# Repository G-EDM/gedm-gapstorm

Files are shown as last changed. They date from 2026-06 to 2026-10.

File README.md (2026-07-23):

</br>
</br>
</br>

```diff
 ______     _______ ______  _______
|  ____ ___ |______ |     \ |  |  |
|_____|     |______ |_____/ |  |  |      

Gapstorm Router
```                                                               

</br>
</br>

# Updates 

07.07.2026 - Updated the links to the most recent freecad project file
* Y-Bracket was missing the holes for the screws (fixed)
* X Ballscrew changed to 400mm
* X Linear rail changed to 300mm
* Some minor changes on the X motor bracket for better assembly

12.07.2026 - Updated the links to the most recent freecad project file
* Mountingbracket for the Y ballscrew support block has changed. It needs to be a little more flexible for adjustments. Replaced the hex nut with T-Nuts and made the screw holes longer.

16.07.2026 - Updated the links to the most recent freecad project file
* Changed the wire outlet. Tube moves now further down and the wire catch area is smaller. Ensure the inlet section is smooth and the 4mm tube goes all the way down.

</br>
</br>

# FreeCAD project file

[Download the G-EDM Gapstorm Router FreeCAD file](https://drive.google.com/file/d/1vxY4w9fKLjqJ0D5UH6L_XMELY-WSWKXv/view?usp=drive_link)
</br>
</br>

# About this Repo

* This Repo contains the files for the mechanical aspect of the G-EDM project. It is not fully finished and not everything is documented. A BOM for the full wire module is included but not for the router. Making the router is not so hard and the components like extrusion, tank, linear rails, ballscrews are all labeled with dimensions inside the FreeCAD project file. The BOM for the wire module is complete and building it is very straight forward. A little youtube video provides a view on the C-Arc from all perspectives.
    
</br>

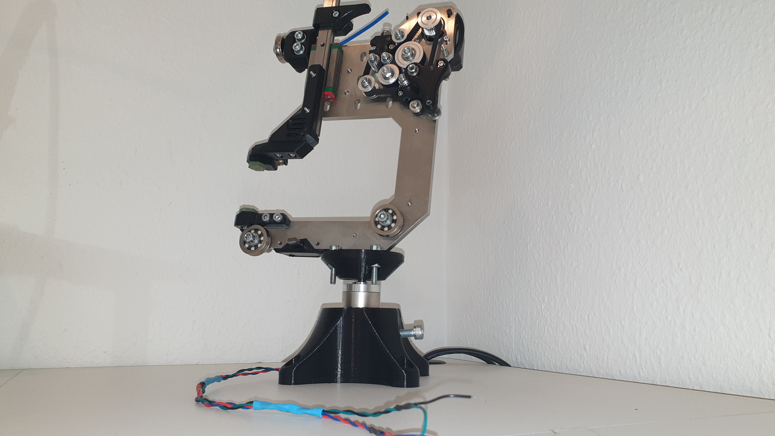
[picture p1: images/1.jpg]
PhantomEDM demo video (https://www.youtube.com/watch?v=hlrt1KqOiBo)

</br>

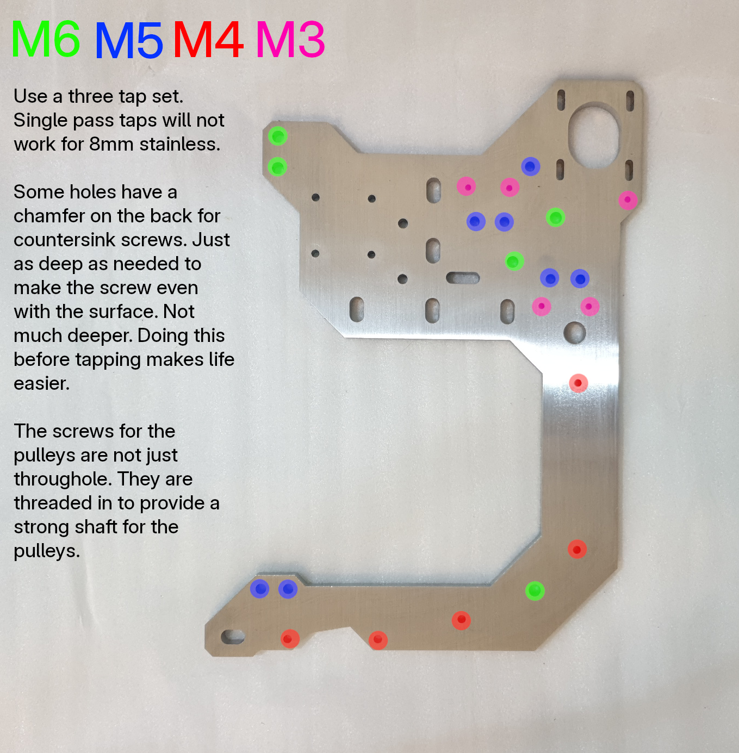
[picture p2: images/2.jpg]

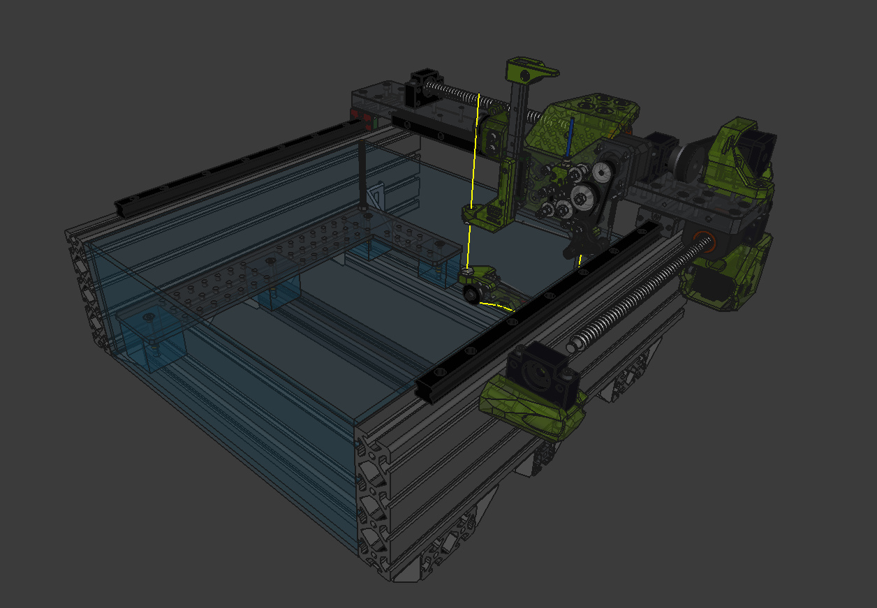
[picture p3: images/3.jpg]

</br>
</br>

# The Files

* The printed files for the wire module are located in the ./gapstorm-wire-module folder.
* The full router is available via google drive. File is too large to upload directly on github. It contains the fully assembled router. Follow the link below for the FreeCAD project.
</br>
</br>

[Download the G-EDM Gapstorm Router FreeCAD file](https://drive.google.com/file/d/1vxY4w9fKLjqJ0D5UH6L_XMELY-WSWKXv/view?usp=drive_link)

</br>
</br>

# Sourcing the C-Arc backbone

* Thanks to Justway.com for sponsoring the backbone prototype. Wouldn't have finished it anytime soon without their help.

* They provide different manufacturing services from CNC machining to 3D printing, injection molding and even wire edm for those that don't have a running G-EDM at home. Ordering is straight forward and they have a friendly customer service that will provide help if there are any questions. For this specific part is is only required to select the material (stainless steel 316/316L), the wanted surface finish and the product description for custom declaration. Surface finish is up to the user. I just went with the cheapest they offer but they do have others to. Black oxide could be a very nice option for parts exposed to an EDM environment.
  
* The backbone is laser cut from 8mm stainless steel. Currently there is no technical drawing to get the threads and chamfers for the countersink screws machined. This needs to be done by hand at the moment. Follow the link below to get to the justway project.

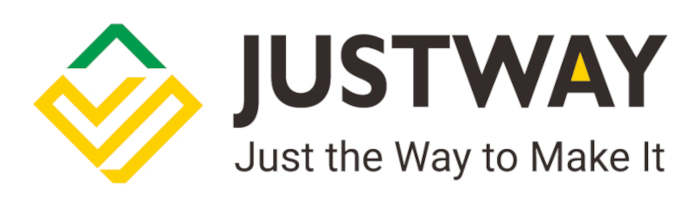
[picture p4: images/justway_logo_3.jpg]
Stainless steel backbone from justway.com (https://www.justway.com/project/shareproject/G_EDM_Gapstorm_Wire_Module_Backbone_82de4ce1.html)


[Stainless steel backbone from justway.com](https://www.justway.com/project/shareproject/G_EDM_Gapstorm_Wire_Module_Backbone_82de4ce1.html)

</br>
See this image for reference:
</br></br>

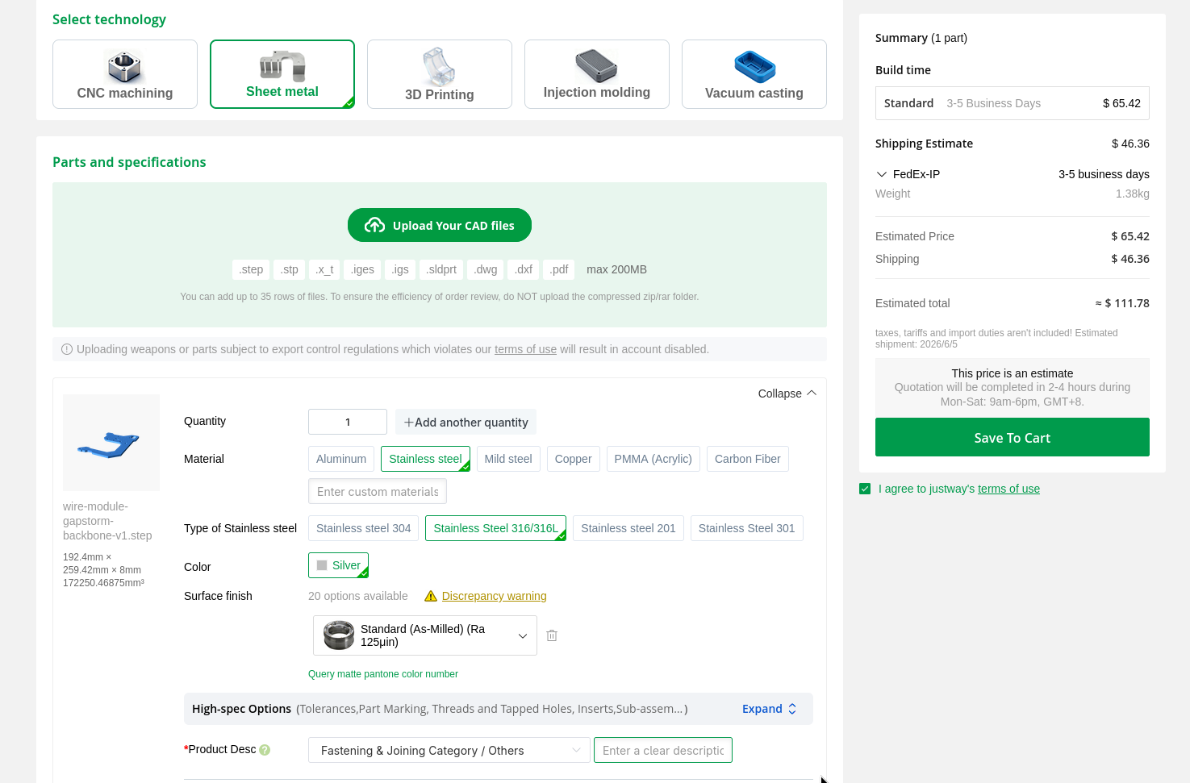
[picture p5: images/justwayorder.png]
justway logo


</br>
</br>

# Sourcing the C-Arc backbone

* Justway.com also sponsored the portal and it can be ordered with the link below

[Aluminum portal from justway.com](https://www.justway.com/project/shareproject/G_EDM_Gapstorm_Portal_a3381aa9.html)

</br></br>

# Tools required

* It is best to drill the chamfers first to reduce the thickness and add the thread after that. Makes life easier. Also don't try single pass taps. They don't work well with 8mm stainless and are almost impossible to get straight. 3 step taps work well. It is stainless so it requires some time for that. Sometimes progress is only a tiny bit and then rotate back and so on.

* M3, M4, M5 and M6 taps are required
* 2,5mm, 3,3mm 4,2mm and 5mm drills 
* Drill or better a drillstand
* Allen keys
* Little blowtorch lighter to remelt some sections on the printed part for increased robustness
    
</br>
</br>

# Tips

* Making the threads needs to be done with care. Getting a broken tap out is very tough without a sinker EDM machine. I broke all taps from M3 to M6 just because I thought "it can take a tiny bit extra force". Take your time with that.

* All screws and washers that are submerged should be made from stainless steel. Normal screw will work but will rust quick.

* The two big bottom V-Groove bearings need a ball replacement with ceramic balls. Size and source is listed in the BOM. This is very important. Firstly the bearing itself is stainless but the balls are not and will rust in no time. And more important the bearings are mounted on the stainless frame which would make the backbone part of the conductive path. To change the balls the sealing can be removed, the palceholder pushed out, balls pushed together and the center part taken out. Replace the balls and put it back together. No hard work and doesn't require special tools.

* The GT2 idlers are very sensitive. Tightening them just a little too much will block the motion. The screws are inserted from the back with good force, then add the idlers and the shims etc. and tighten the self locking nuts just enough to make the idler stop moving along the screw but not until motion is blocked. A tiny bit extra is ok. 

* The printed inlet and outlet require good postprocessing. The inner channel should be as smooth as possible or the wire will get stuck.

* Alignment is up to the users. Basic alignment is to first ensure the bottom V Groove bearing pulls the wire in the center of the bottom nozzle. Look from below and adjust the bearing as needed until the wire is in the center. Then move the upper guide to the side and adjust to top V Groove bearing until the wire is straight. Then put the upper guide into place with the wire going through it and loosen the screws. Put the wire under tension and let the guide self adjust. The MGN15 should also be adjusted. While moving the slide up and down the wire should not move. I personally don't care about it too much. The wire should move smoothly along the nozzles without any rough or sharp feelings while pulling.
    
</br>
</br>

# Technical drawings

Portal (Aluminum):
</br>

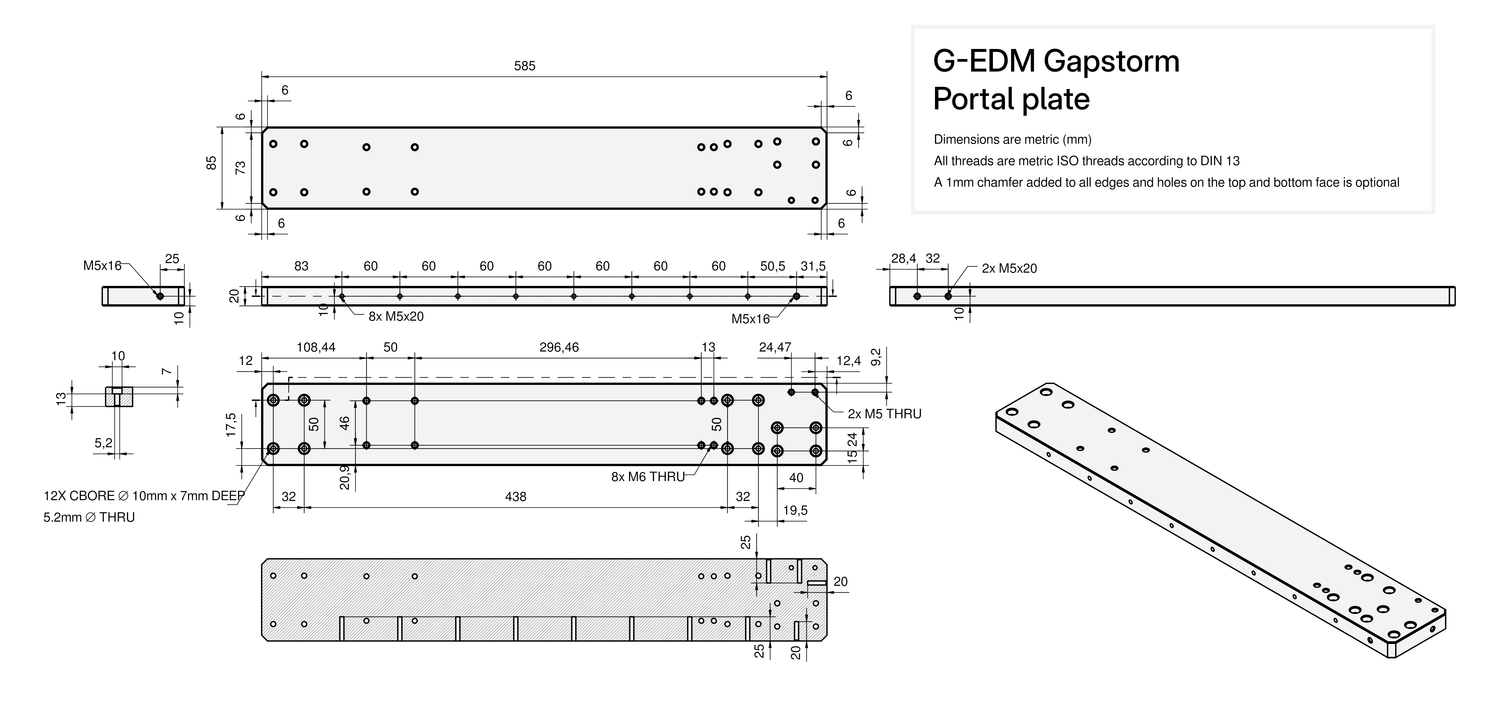
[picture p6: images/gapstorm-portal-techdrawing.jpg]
portal plate technical drawing


</br>
</br>

# Wiki (Work in progress)

[A little Wiki can be found here](https://gedm.org/wiki)

</br>
</br>

# Donations

    Become a supporter now and help accelerate development with a donation. Circuit boards, electronic components, hardware and software development are just some of the costs that need to be covered. Without the support of the community, this wouldn't be possible.
    Every supporter receives an entry with their name or alias in the credit list displayed on the firmware boot screen.
    Click the image to support the project with a little paypal donation.



</br>
</br>

# Legal notes

    The author of this project is in no way responsible for whatever people do with it.
    No warranty. 

</br>   
</br>

# Credits to whom credits belong

    Thanks for the support and help to keep the project going.

    @ Tanatara
    @ 8kate
    @ Ethan Hall
    @ Esteban Algar
    @ 666
    @ td1640
    @ Nikolay
    @ MaIzOr
    @ DANIEL COLOMBIA
    @ charlatanshost
    @ tommygun
    @ renyklever
    @ Zenitheus
    @ gerritv
    @ cnc
    @ Shrawan Khatri
    @ Alex Treseder
    @ VB
    @ AndrewS
    @ TK421
    @ sarnold04

</br>   
</br>

# Responsible for the content provided

    Lautensack Roland (Germany)

</br>   
</br>

# License

    All files provided are for private use only if not declared otherwise and any form of commercial use or redistribution of the protected files is prohibited.

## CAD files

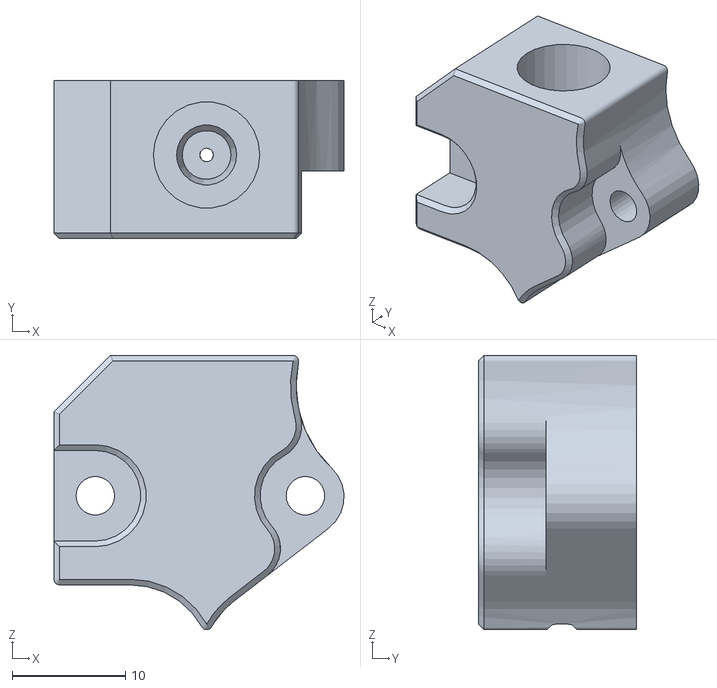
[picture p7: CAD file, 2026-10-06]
gapstorm-wire-module/belt-drive-outlet-v4.stl
25.6 x 14.0 x 24.2

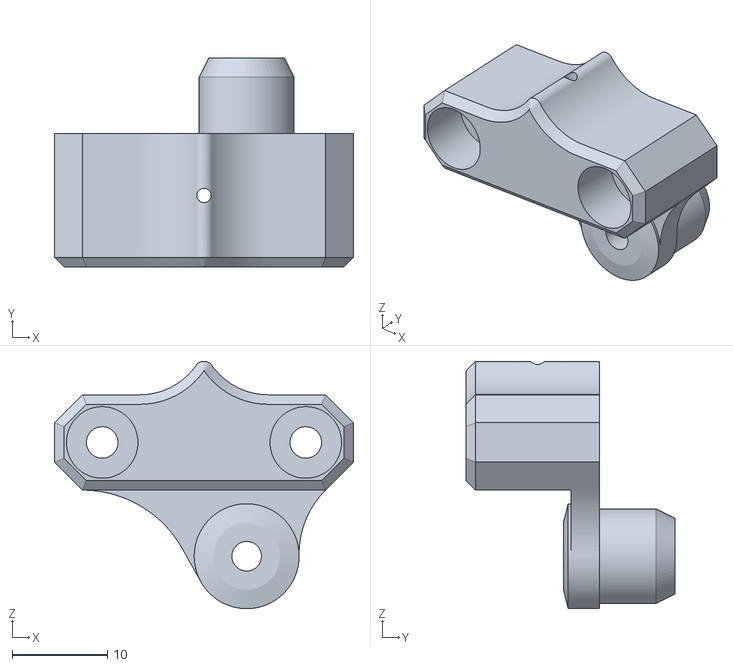
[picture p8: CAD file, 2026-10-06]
gapstorm-wire-module/belt-drive-inlet-v4.stl
31.3 x 21.9 x 25.9

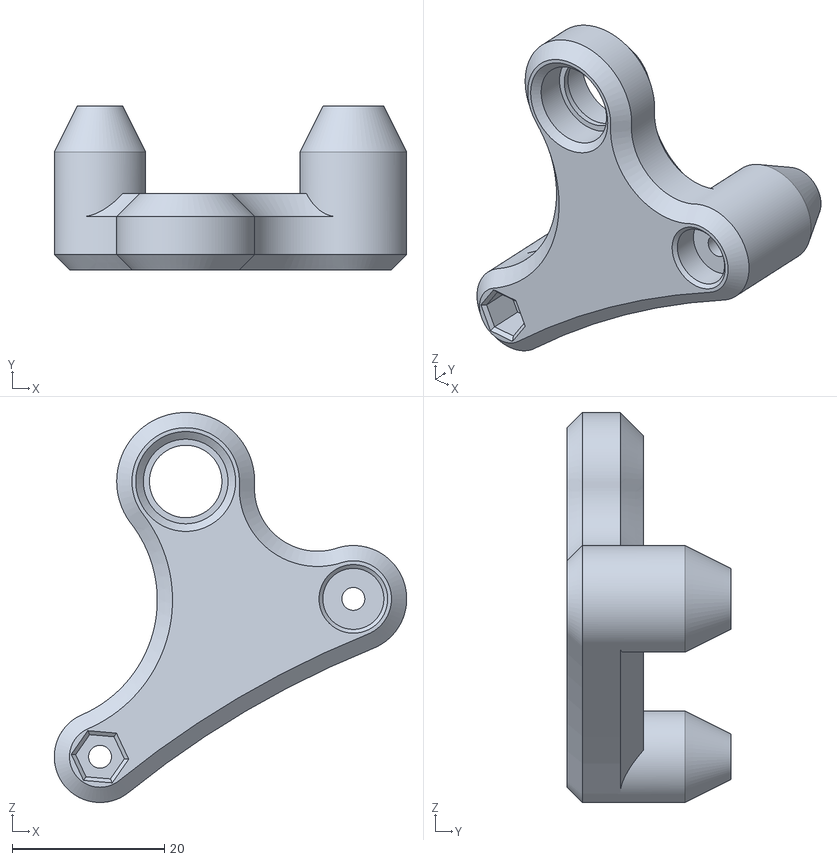
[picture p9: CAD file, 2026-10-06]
gapstorm-wire-module/tensioner-pulling-side-v5.stl
46.2 x 21.5 x 51.2

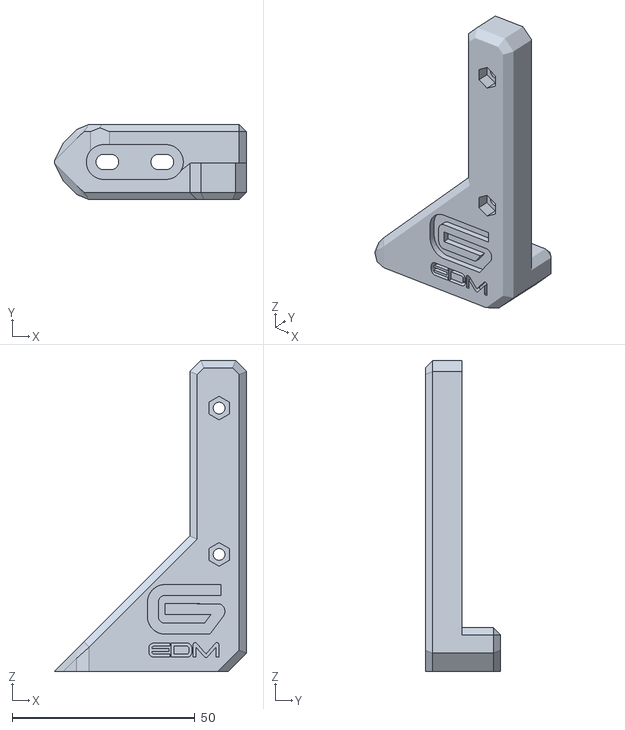
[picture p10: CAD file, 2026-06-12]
gapstorm-wire-module/top-wire-guide-bracket-v2.stl
52.5 x 20.6 x 85.0

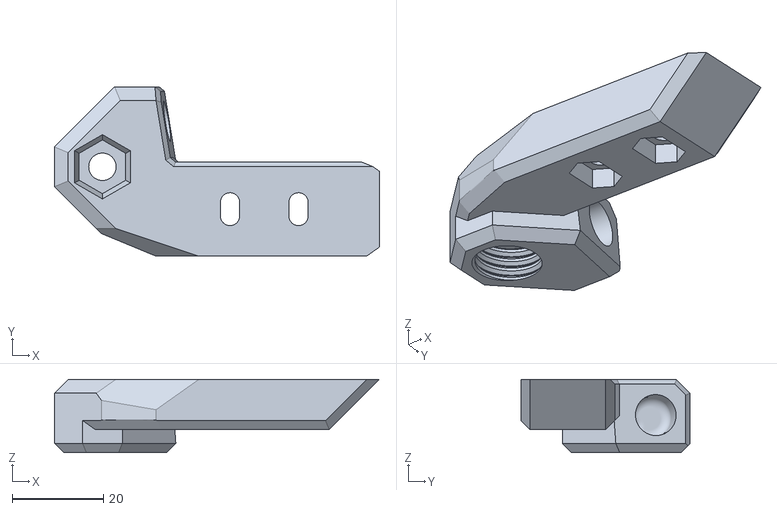
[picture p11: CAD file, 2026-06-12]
gapstorm-wire-module/top-wire-guide-v3.stl
71.2 x 37.1 x 16.0

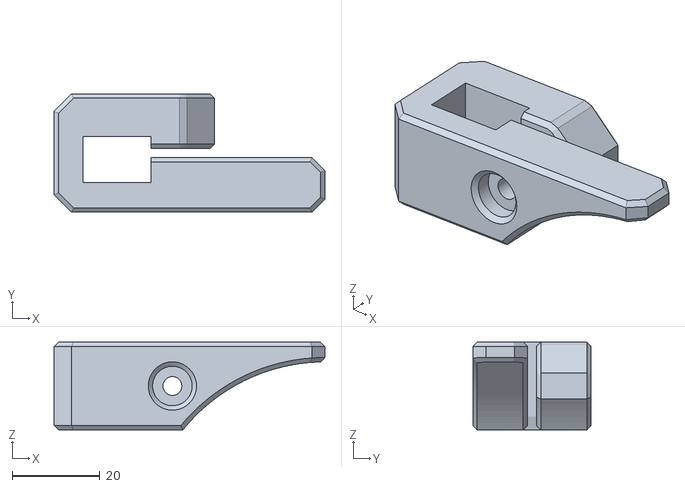
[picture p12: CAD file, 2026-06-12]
gapstorm-wire-module/mgn-15-handle-v2.stl
61.8 x 27.0 x 20.0

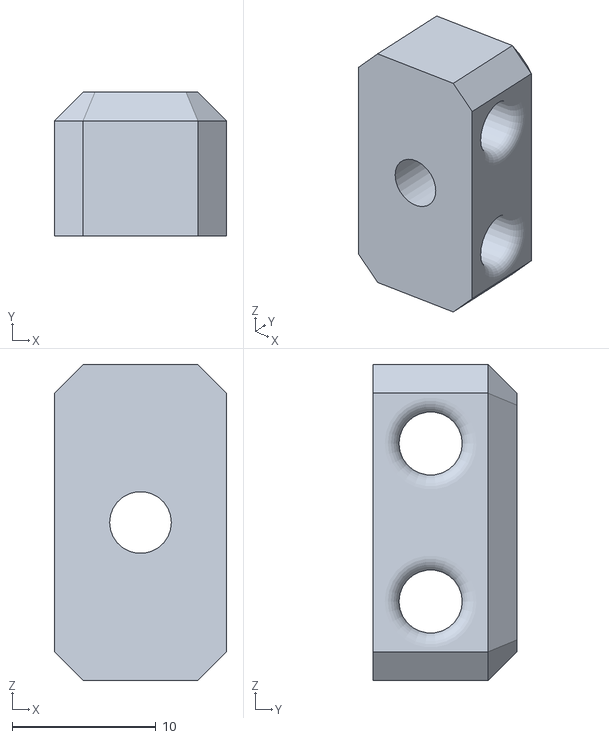
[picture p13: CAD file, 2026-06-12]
gapstorm-wire-module/tube-routing-bracket.stl
12.0 x 10.0 x 22.0

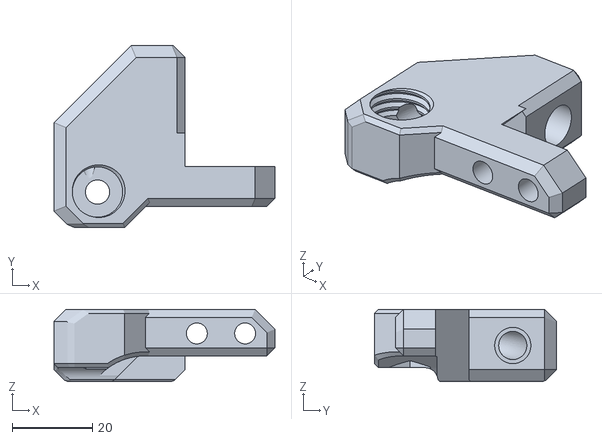
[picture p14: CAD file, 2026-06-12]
gapstorm-wire-module/bottom-wire-guide-v2.stl
54.9 x 45.2 x 18.0

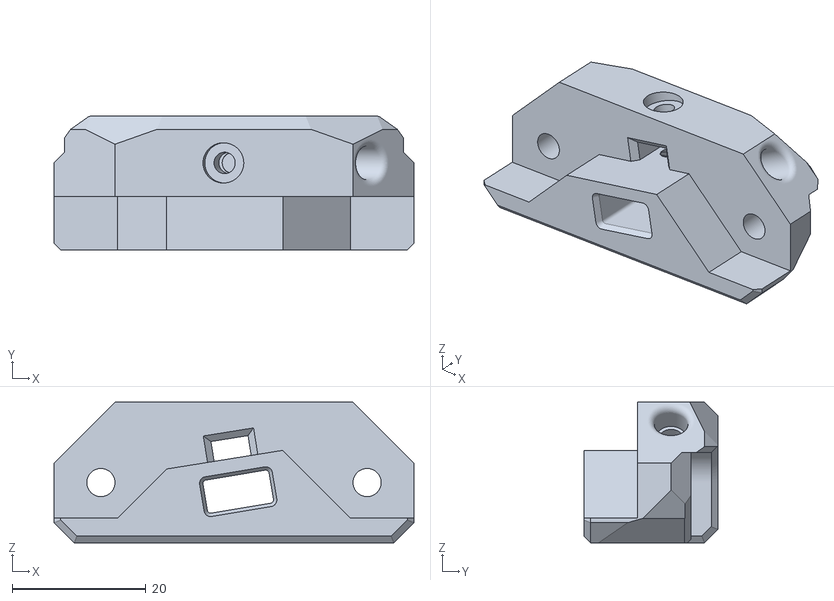
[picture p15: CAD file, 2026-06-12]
gapstorm-wire-module/current-contact-bracket-v5.stl
53.7 x 20.0 x 21.0

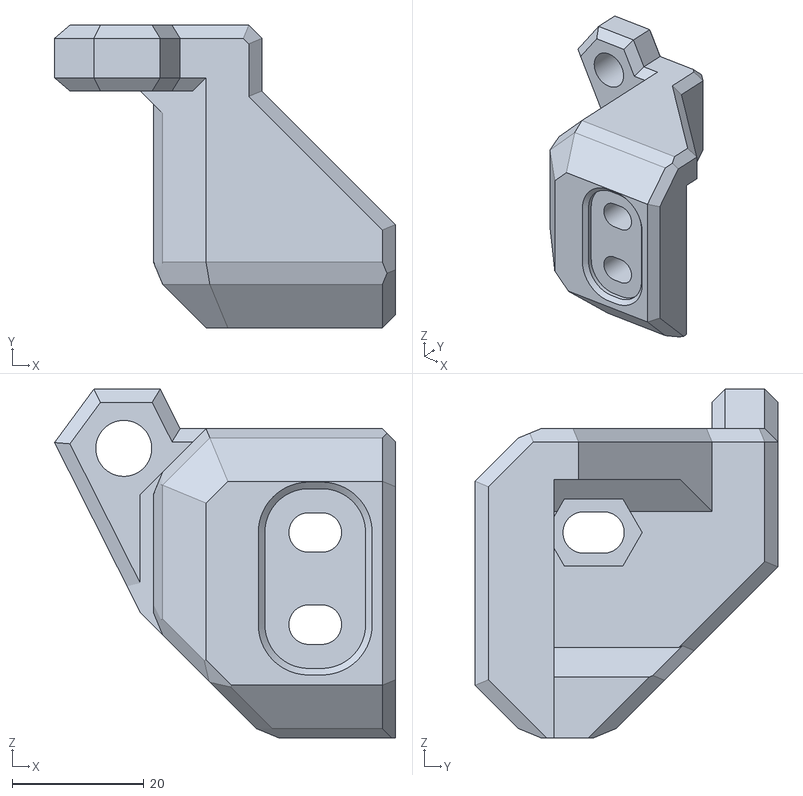
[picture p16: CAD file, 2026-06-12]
gapstorm-wire-module/top-left-bearing-bracket.stl
51.8 x 46.0 x 53.0
